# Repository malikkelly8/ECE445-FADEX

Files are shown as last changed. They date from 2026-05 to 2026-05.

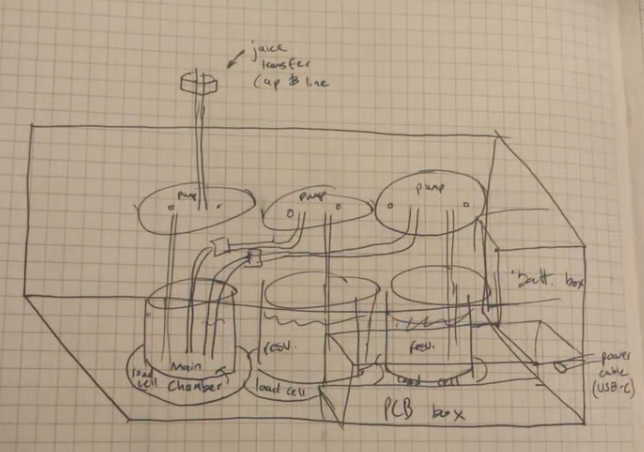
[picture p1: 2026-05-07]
Images/homebasedDesign.png

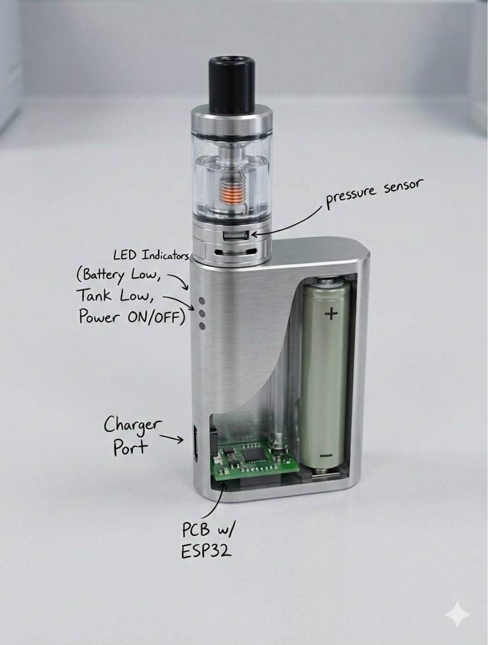
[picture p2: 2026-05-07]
Images/vape.jpg

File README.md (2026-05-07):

# FadeX - Automated Nicotine Tapering System

FadeX is an adaptive nicotine tapering prototype developed for ECE 445. The project explores a safer, feedback-based way to reduce nicotine concentration over time while preserving the user's familiar puff routine. Instead of forcing large manual concentration jumps, FadeX uses puff behavior, user check-ins, and embedded control logic to calculate a gradual taper and prepare a target mixture.

## Team Members

- **Malik Kelly** - Tapering algorithm, app/chatbot interface, ESP32 integration support
- **Justin Leith** - Project management, mechanical design, optical sensing support
- **Ian Zentner** - MCU logic, PCB design, hardware integration

## Final Prototype Overview

The final FadeX prototype centers on a **Homebase ESP32** that coordinates communication, dosing logic, pump control, load-cell feedback, and concentration sensing. A simplified **Handheld ESP32** is used to record puff activity and send puff-session data to the homebase. The system was demonstrated using a nicotine surrogate rather than real nicotine for safety.

The final architecture includes:

- **Homebase Controller:** ESP32-based controller that runs the tapering algorithm, receives puff data, controls pumps, reads load cells, and manages safety logic.
- **Handheld Puff Input:** Simplified ESP32 handheld with a puff button that records puff count/session duration and sends data to the homebase through ESP-NOW.
- **Fluid Delivery System:** Peristaltic pumps used to deliver concentrate/surrogate and diluent into a mixing reservoir.
- **Load-Cell Feedback:** HX711 load-cell amplifiers used to tare containers and verify delivered liquid mass.
- **UNCS Concentration Sensing:** UV LED and photodiode circuitry used to support concentration feedback for the vitamin C/ascorbic acid surrogate.
- **User Interface:** Blynk dashboard and/or serial-based FadeX Chatbot used to display system state, collect check-in responses, and guide the demo flow.

## Tapering Algorithm

FadeX calculates the next concentration using puff behavior, treatment week, user survey feedback, and safety limits. The algorithm combines objective usage data with simple self-report inputs so that the taper can slow down or stabilize when relapse risk appears higher.

Core algorithm ideas:

- Puff count and puff duration are collected from the handheld or demo input.
- The user check-in classifies the session as `Better`, `Neutral`, `Struggling`, or `Worse`.
- Trigger questions are only asked when the user reports `Struggling` or `Worse`.
- Scenario codes classify the current user state and guide tapering behavior.
- The next concentration is safety-clamped before pump volumes are calculated.
- Pump delivery is verified using load-cell feedback instead of relying only on timed pumping.

Example equations:

```text
A = 1.0 + S + (1.0 - Mu)
C_next = clamp(C_current - 0.28A, 0.5%, 5.0%)
V_concentrate = (C_next / 5.0) * V_total
V_diluent = V_total - V_concentrate
```

## Repository Structure

```text
/Code/              Firmware sketches, tests, and integration code
/Images/            Diagrams, presentation graphics, screenshots, and verification visuals
/Notebook_Entries/  Chronological lab notebook entries and engineering logs
/PCB/          PCB schematics, pinout references, and hardware design files
```

Some folders may contain uploaded final report materials, figures, or archived versions of earlier designs.

## Key Subsystem Tests

The project was developed through modular tests before final integration:

- ESP32 programming and MAC address identification
- ESP-NOW handheld-to-homebase puff communication
- Pump direction, flow-rate, and volume delivery tests
- Load-cell calibration and tare verification
- Water-by-weight dispense testing
- UV LED PWM output testing
- Photodiode ADC readout testing
- Blynk dashboard and FadeX Chatbot workflow testing
- Final integrated dosing and demo flow testing

## Safety Notes

The course prototype used water and vitamin C/ascorbic acid surrogate solutions instead of nicotine for safety. The firmware and demo flow include safety-oriented behavior such as load-cell taring, staged pump pulses, maximum mixing-volume checks, and emergency stop commands. The homebase controller is responsible for safety-critical pump control rather than relying only on the app interface.

## Project Tracking and Engineering Notebook

- `/Notebook_Entries/` contains chronological lab notebook entries documenting objectives, design decisions, testing, debugging, and final outcomes.
- `/Images/` contains visuals used for reports, slides, flowcharts, and verification documentation.
- The GitHub Project/Kanban board was used during development to track subsystem progress and remaining demo tasks.

## Final Deliverables

Final project materials include the final paper, video assignment, lab notebook entries, subsystem test code, algorithm visuals, and final demo documentation.

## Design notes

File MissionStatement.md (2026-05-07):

# FadeX Mission Statement

FadeX exists to explore a safer, more adaptive path for nicotine tapering by combining user behavior data, embedded control, and feedback-based fluid delivery. Traditional cessation tools often separate nicotine reduction from the habitual puff routine, while manual tapering forces users into large concentration jumps that can increase withdrawal and relapse risk. FadeX addresses this gap by using puff activity, user check-ins, and a controlled mixing system to calculate gradual concentration changes that are easier for the user to follow.

Our mission is to demonstrate that nicotine reduction can be automated, personalized, and safety-aware. The FadeX prototype uses a homebase ESP32 controller, handheld puff input, pump-based liquid delivery, load-cell mass verification, and optical concentration sensing with a safe surrogate solution. This system is designed to show how future cessation devices could reduce nicotine exposure over time while preserving behavioral continuity, improving transparency through a user interface, and maintaining firmware-level safety limits.

FadeX is not intended to encourage vaping or recreational nicotine use. Its purpose is to support cessation-focused engineering by showing how adaptive algorithms, sensor feedback, and embedded safeguards can work together to guide users toward lower dependence.

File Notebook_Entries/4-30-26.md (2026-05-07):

## Entry 4: Final Presentation and Feedback

**Date:** 4/30/26  

**Objective:** Present the final FadeX project and receive feedback from course staff.

**Work Completed:**  
The team delivered the final presentation to explain the project motivation, design, implementation, testing, and conclusions. The presentation described the shift from the original full vape concept to a safer homebase-centered prototype using pumps, load cells, ESP32 control, and app/serial interaction. We explained the adaptive algorithm, including how puff behavior and user state affected concentration decisions. We also discussed safety measures such as using a surrogate instead of nicotine, load-cell verification, pump limits, and emergency stop behavior.

**Results / Decisions:**  
The final presentation helped clarify the completed design and the remaining limitations. The team showed that FadeX was not just a mechanical mixing system but an adaptive control system that connected user behavior to physical dosing. Feedback from the presentation helped guide what needed to be emphasized in the final paper, especially the actual implemented design, verification results, and future work.

**Next Step:**  
Update the final paper to match the final implemented system and include accurate descriptions of hardware, software, testing, and limitations.

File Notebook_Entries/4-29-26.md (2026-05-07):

## Entry 3: Final Presentation Preparation

**Date:** 4/29/26  

**Objective:** Prepare the final presentation slides and organize the project story for a clear technical presentation.

**Work Completed:**  
The team prepared the final presentation by organizing the project into introduction, objective, design, results, and conclusion sections. I focused on the objective and algorithm-related slides, including the problem being solved, the adaptive tapering logic, the main equations, scenario codes, and how the hardware subsystems supported the algorithm. The presentation emphasized the flow from puff behavior to algorithm decision to physical fluid delivery. The team also refined visuals so that graphs, flowcharts, equations, and stage diagrams were readable and did not overlap.

**Results / Decisions:**  
The team decided that the presentation should be organized around the algorithm flow rather than only listing hardware subsystems. This made it easier to explain why load cells, pumps, app inputs, and the UV/photodiode sensor mattered. The final presentation connected the design decisions back to the original problem of helping users taper nicotine without large manual concentration jumps.

**Next Step:**  
Rehearse the presentation, finalize slide visuals, and prepare for questions about implementation changes, verification, and safety.

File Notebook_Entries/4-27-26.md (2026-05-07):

## Entry 1: Final Demo Setup and System Readiness

**Date:** 4/27/26  

**Objective:** Prepare the FadeX prototype for final demonstration and verify that the most important subsystems were ready to show.

**Work Completed:**  
The team reviewed the final demo setup and checked which subsystems could be demonstrated reliably. The focus was on showing the homebase control system, pump delivery behavior, load-cell feedback, app or serial interaction, and the adaptive algorithm. Since the project had changed from the original fully integrated vape concept into a safer homebase-centered demonstration, the final setup emphasized controlled fluid mixing, puff-data input, and algorithm-driven concentration adjustment. We also reviewed backup plans in case Blynk connectivity, ESP-NOW communication, or pump/load-cell integration failed during the demo.

**Results / Decisions:**  
The team decided that the final demo should prioritize reliability and clarity. The most important story was that FadeX could collect usage information, calculate a next concentration, and physically dose liquid using feedback rather than blind timing alone. The demo sequence was kept controlled so that the evaluators could clearly see each major subsystem contribute to the final result.

**Next Step:**  
Run final checks on the ESP32 firmware, pumps, load cells, communication path, and user-facing interface before presenting.

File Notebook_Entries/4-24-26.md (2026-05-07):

## Entry 5: Final Demo Risk Review

**Date:** 4/24/26  

**Objective:** Identify the highest-risk integration issues remaining before the final demo.

**Work Completed:**  
After the mock demo and presentation preparation, the team reviewed what still needed to work reliably for the final demonstration. The main risks were reliable pump delivery, load-cell calibration, communication between handheld and homebase, Blynk connectivity, clear demo steps, and concentration verification with the UV/photodiode sensor. We also discussed fallback options, including using the serial monitor as a backup interface if Blynk or wireless communication became unreliable.

**Results / Decisions:**  
The team decided that the final demo needed a controlled sequence instead of an open-ended test. The demo should show puff input, algorithm calculation, app/chatbot feedback, pump delivery, and safety behavior in a repeatable order. The team also recognized that fallback paths were important because wireless systems and hardware integration could fail under demo conditions.

**Next Step:**  
Prepare a final demo script, continue hardware debugging, and make sure each subsystem has a working backup test.

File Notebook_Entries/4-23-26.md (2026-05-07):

## Entry 4: Blynk Dashboard and Chatbot Demo Flow

**Date:** 4/23/26  

**Objective:** Improve the user-facing demo by using Blynk and the FadeX Chatbot to guide the dose workflow.

**Work Completed:**  
I worked on the app/demo flow using Blynk virtual pins and the FadeX Chatbot terminal interface. The dashboard included values such as current concentration, next concentration, puff count, puff duration, survey score, trigger code, scenario code, nicotine volume, diluent volume, money saved, milestone progress, clinician override, prime command, run dose command, and puff button. The chatbot was designed to guide the user through a session by showing current status, collecting survey input, asking about triggers only when needed, and preparing the dose calculation. I also worked through issues with terminal clearing, repeated messages, and the order of chatbot prompts.

**Results / Decisions:**  
The team decided that the Blynk dashboard would be the main app interface, while the chatbot would make the demo easier to follow. The app would display system values, and the chatbot would explain what the system was doing step by step. However, the homebase ESP32 would still remain responsible for dosing logic and safety-critical pump control.

**Next Step:**  
Refine the chatbot prompt order, reduce repeated terminal output, and ensure the run-dose workflow asks the right questions before calculating the next concentration.

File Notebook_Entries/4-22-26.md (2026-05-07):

## Entry 3: Algorithm and Stage Visual Development

**Date:** 4/22/26  

**Objective:** Create visual materials that clearly explained the adaptive algorithm and the hardware stages for the mock/final presentation.

**Work Completed:**  
I worked on presentation graphics for the algorithm overview and stage-based design slides. The algorithm was organized into major stages: detecting puff activity, collecting survey/user state information, calculating the next concentration, and dispensing/verifying the final mixture. I also created or refined visuals for the adaptive decision table, equations, and stage-specific hardware functions. Several figures required polishing so that text fit inside boxes, arrows were not cut off, and graphs did not cover important labels.

**Results / Decisions:**  
The team decided that visuals would be essential for explaining the project quickly. The algorithm overview slide needed to include the main equations and variable definitions, while the stage slides needed to show how the hardware interacted with the software. This helped turn a complex system into a presentation sequence that was easier to follow.

**Next Step:**  
Finalize the algorithm graphics, stage visuals, and equation/definition slide for the mock presentation and final report.

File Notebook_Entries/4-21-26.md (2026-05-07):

## Entry 2: Mock Presentation Slide Planning

**Date:** 4/21/26  

**Objective:** Build a short mock presentation that explained the project objective, algorithm, and hardware flow clearly.

**Work Completed:**  
The team divided mock presentation responsibilities across the required slide categories: title, introduction, objective, design, and conclusion. I focused on the objective slide and the algorithm-based design slides. The presentation flow was planned around explaining the high-level algorithm first, then breaking down each hardware subsystem based on where it appears in the algorithm. This included puff detection and usage tracking, adaptive decision logic, fluid delivery with pumps/load cells, and concentration feedback using the UV/photodiode system.

**Results / Decisions:**  
The team decided that the presentation should explain the algorithm as the main story and then show how the hardware supports each step. This made the presentation more coherent than listing hardware blocks separately. It also helped connect the user problem, software algorithm, and physical mixing system in a way that non-specialists could follow.

**Next Step:**  
Create and polish visuals for the objective slide, algorithm overview, stage-based hardware slides, and final conclusion.

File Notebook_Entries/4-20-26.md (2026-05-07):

## Entry 1: Mock Demo Preparation

**Date:** 4/20/26  

**Objective:** Prepare a focused mock demo that showed meaningful subsystem progress and clarified what still needed to be finished before the final demo.

**Work Completed:**  
The team reviewed the remaining hardware, software, and presentation tasks for the mock demo week. We focused on demonstrating the most important parts of the system: ESP32 control, pump behavior, load-cell sensing, app or serial interface interaction, and the adaptive algorithm flow. Since not every subsystem was fully integrated yet, the goal was to present working pieces clearly and explain how they would connect in the final system. I worked on organizing the algorithm explanation and app/demo flow so that the control logic could be understood even if the hardware was still being debugged.

**Results / Decisions:**  
The team decided that the mock demo should not try to hide unfinished work. Instead, it should show current progress, identify remaining blockers, and demonstrate that the project had a realistic path to final integration. The mock demo helped reveal which parts needed the most attention before the final week, especially pump/load-cell integration, communication reliability, and a clean user-facing demo flow.

**Next Step:**  
Use mock demo feedback to prioritize final integration tasks and prepare a reliable final demo sequence.

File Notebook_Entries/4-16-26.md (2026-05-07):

## Entry 4: Parts Procurement and Nicotine Contingency Planning

**Date:** 4/16/26  

**Objective:** Review remaining parts procurement issues and develop a backup plan if nicotine could not be used safely in the lab.

**Work Completed:**  
The team discussed uncertainty around using real nicotine and whether safer substitute materials would be needed for the final demo. We also reviewed component sourcing, including possible substitutions for MOSFETs, LED drivers, USB-C parts, and other hardware. Since some parts were coming from different vendors, including DigiKey and Amazon, the team discussed how to keep progress moving even if the final PCB or specialty components were delayed.

**Results / Decisions:**  
The team recognized that a nicotine surrogate might be necessary for safety and feasibility. This decision later supported the use of vitamin C/ascorbic acid as a measurable surrogate for concentration testing. The team also decided to prioritize parts that enabled subsystem testing, even if the exact final hardware was not fully available yet.

**Next Step:**  
Finalize the parts list, continue ordering needed components, and confirm with TAs or course staff what materials could be used safely for demonstration.

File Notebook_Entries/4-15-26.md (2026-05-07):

## Entry 3: Blynk App and User Interface Planning

**Date:** 4/15/26  

**Objective:** Develop the app-side plan for displaying system status and collecting user inputs during the demo.

**Work Completed:**  
I worked on planning the Blynk dashboard and how it would support the FadeX demo. The dashboard needed to show values such as current concentration, next concentration, daily puff count, daily puff duration, survey score, trigger code, scenario code, nicotine volume, diluent volume, milestone progress, and money saved. I also considered how the app could be used to start a dose run, prime pumps, and display algorithm outputs. Since app connectivity could become a risk, I also considered using the serial monitor as a backup control interface.

**Results / Decisions:**  
The team decided that the app should be useful for user-facing interaction but that the ESP32 firmware should remain responsible for safety-critical dosing. This meant the app could collect inputs and display outputs, while the homebase controller would still calculate and enforce dose behavior. Blynk was selected as the main app option because it allowed quick dashboard creation and virtual pins for data exchange.

**Next Step:**  
Create Blynk datastreams, connect the ESP32 to the dashboard, and test whether dashboard values update reliably.

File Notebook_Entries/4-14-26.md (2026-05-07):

## Entry 2: Skeleton Code Test Planning

**Date:** 4/14/26

**Objective:** Define skeleton code tests that could verify basic hardware functionality before full system integration.

**Work Completed:**  
The team discussed a set of small ESP32 test programs for hardware bring-up. These included an ESP32 programming test using a blinking output pin, PWM output for the UV LED driver, ADC input for the photodiode circuit, motor driver tests for the pumps, and HX711/load-cell calibration tests. The goal was to confirm that each circuit could be controlled or read by the ESP32 before merging everything into the final firmware. These tests would also produce simple evidence such as oscilloscope waveforms, serial monitor readings, and visible pump activation.

**Results / Decisions:**  
The team decided that subsystem skeleton code would be safer and easier to debug than immediately building one large program. Each test would isolate one subsystem, making it easier to identify whether a problem came from wiring, code, power, or hardware. This approach became important for later debugging when pump pins, load-cell readings, and UV/photodiode behavior needed to be verified individually.

**Next Step:**  
Write or adapt skeleton code for ESP32 GPIO, pump motor drivers, load cells, UV LED PWM, and photodiode ADC readings.

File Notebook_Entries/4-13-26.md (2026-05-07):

## Entry 1: Mock Demo Planning and Kanban Review

**Date:** 4/13/26  

**Objective:** Prepare for the mock demo by reviewing project status, identifying incomplete tasks, and organizing the remaining hardware/software work.

**Work Completed:**  
The team reviewed the GitHub Kanban board to determine what had been completed and what still needed to be finished before the mock demo. We identified key tasks including finishing the vape/demo layout, completing subsystem skeleton code, and updating the Kanban board with progress. The team discussed how exam and homework schedules would affect the pace of work, so the goal was to focus on practical tasks that would most directly support the demo. I focused on the software and app-facing side of the project, including how the user interface would interact with the ESP32 system.

**Results / Decisions:**  
The team decided that the mock demo should focus on showing working subsystem behavior rather than trying to present the entire final system as complete. The Kanban board became the main snapshot of project progress and helped prioritize the highest-impact tasks.

**Next Step:**  
Continue updating the Kanban board and focus on skeleton tests for the major hardware subsystems.

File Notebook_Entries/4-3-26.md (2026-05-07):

## Entry 4: Hardware Testing Strategy and Breadboard Planning

**Date:** 4/3/26  

**Objective:** Plan the hardware tests needed before full PCB integration and decide how to use breadboard testing effectively.

**Work Completed:**  
The team discussed PCB printing, ESP32 programming, power wiring, and whether to begin testing on a breadboard while waiting for PCB hardware. We identified that breadboard testing could help verify the most important functions early, including pump direction, pump flow rate, motor driver logic, load-cell communication, and ESP32 pin behavior. We also discussed the importance of matching breadboard pins to expected PCB pins as much as possible so that test code could later transfer to the final board with minimal changes.

**Results / Decisions:**  
The team decided that breadboard testing was necessary to reduce schedule risk. Waiting for the PCB before testing every subsystem would create too much uncertainty. The plan was to build modular tests first, then later merge working subsystem code into the final integrated homebase firmware.

**Next Step:**  
Begin breadboard tests for pump drivers and load cells, then record results for verification and debugging.

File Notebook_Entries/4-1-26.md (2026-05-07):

## Entry 3: Verification and Flowchart Planning

**Date:** 4/1/26  

**Objective:** Develop verification tasks and improve the visual explanation of the FadeX algorithm and subsystem flow.

**Work Completed:**  
The team discussed verification planning, flowcharts, and how to show hardware/software integration clearly. I worked on organizing the algorithm flow into a visual structure that could be used later for slides and documentation. The flow needed to show how puff detection, user state, usage trends, concentration calculation, pump volume calculation, and dashboard updates were connected. The team also discussed verification tests for different subsystems, such as ESP32 programming, pump activation, load-cell readings, UV LED PWM output, photodiode ADC readings, and wireless communication.

**Results / Decisions:**  
The team decided that each subsystem needed a clear verification path. The algorithm flowchart would help explain the software side, while hardware verification tests would prove that each physical subsystem could support the algorithm. This work also helped prepare for progress demo and final presentation materials.

**Next Step:**  
Create refined visuals for the algorithm flow and begin writing or collecting skeleton test code for hardware verification.

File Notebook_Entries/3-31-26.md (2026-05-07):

## Entry 2: GitHub Repository and Kanban Access

**Date:** 3/31/26  

**Objective:** Improve project coordination by making sure team members could access shared code and task-tracking resources.

**Work Completed:**  
The team discussed GitHub repository access, Kanban board visibility, and how to keep code and documentation organized. I worked on resolving access issues so that I could view or contribute to the repository and project board. The team also discussed whether updates should be shared through GitHub, screenshots, text files, or exported figures. Since the project involved multiple subsystems and several people working in parallel, having a shared task board became important for tracking what was finished, what was blocked, and what still needed to be assigned.

**Results / Decisions:**  
The team decided that the Kanban board and GitHub repository should become the main coordination tools for software, verification tasks, and documentation. This helped reduce confusion about task ownership and made it easier to prepare evidence for progress demos and the final report.

**Next Step:**  
Continue updating the Kanban board with hardware tests, software tasks, app work, and documentation progress.

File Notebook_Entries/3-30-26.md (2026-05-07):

## Entry 1: Individual Progress Report Preparation

**Date:** 3/30/26  

**Objective:** Prepare the individual progress report by documenting personal contributions, current project status, and remaining risks.

**Work Completed:**  
I worked on organizing my individual progress report for the course deadline. The report summarized my contributions to the FadeX project, especially the adaptive tapering algorithm, app/interface planning, flowchart development, and software-side integration planning. I also reviewed the project schedule and compared the original design document goals with the current implementation status. This helped identify which parts of the project were progressing and which parts still needed more testing, such as pump control, load-cell calibration, wireless communication, and concentration sensing.

**Results / Decisions:**  
The progress report helped clarify my role in the project. My main responsibilities were centered on algorithm development, user interaction, app/dashboard planning, and connecting the software logic to the hardware subsystems. It also made clear that the project needed to move quickly from planning into subsystem testing.

**Next Step:**  
Submit the individual progress report and continue developing the algorithm and app-side workflow for the upcoming demos.

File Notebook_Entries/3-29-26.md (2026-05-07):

## Entry 4: Breadboard-to-PCB Transition Planning

**Date:** 3/29/26  

**Objective:** Plan how breadboard testing would transition into PCB testing without changing the software structure too much.

**Work Completed:**  
The team discussed how to organize code and hardware tests so that the same firmware concepts could work on both breadboard and PCB setups. We identified that pin definitions should be isolated near the top of each sketch so that changing from breadboard pins to PCB pins would be straightforward. We also discussed the need for small subsystem sketches, such as pump tests, load-cell calibration tests, UV LED PWM tests, photodiode ADC tests, and ESP32 communication tests.

**Results / Decisions:**  
The team decided that subsystem test sketches would be important for debugging. Instead of immediately building one large final program, the project would benefit from smaller test programs that each verified a single hardware function. This decision later made it easier to debug pumps, load cells, ESP-NOW, Blynk, and UNCS separately before integration.

**Next Step:**  
Begin creating skeleton code tests for each hardware subsystem and prepare for the individual progress report due the following week.

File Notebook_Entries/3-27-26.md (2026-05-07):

## Entry 3: Algorithm Flowchart and Documentation Update

**Date:** 3/27/26  
**Objective:** Improve documentation of the adaptive tapering algorithm and make the algorithm easier to explain for future reports and presentations.

**Work Completed:**  
The team worked on making the algorithm easier to visualize and explain. The algorithm was organized around several major steps: detecting puff activity, measuring puff duration and count, collecting user state information, computing the next concentration, applying safety limits, calculating pump volumes, and updating the user interface. This helped connect the software algorithm to the physical hardware subsystems, since puff data came from the handheld, concentration calculations ran on the homebase, and final dosing was performed by pumps and verified with sensors.

**Results / Decisions:**  
The team decided that the algorithm should be presented as a staged flow rather than just equations. This made it easier to explain how hardware inputs influenced the final concentration. The flowchart also helped reveal which variables needed to be displayed in the app or serial interface, including current concentration, next concentration, puff count, puff duration, scenario code, and dose volumes.

**Next Step:**  
Create or refine an algorithm flowchart and use it to guide software implementation.

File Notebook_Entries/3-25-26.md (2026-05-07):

## Entry 2: PCB Order and Hardware Availability Planning

**Date:** 3/25/26  

**Objective:** Track PCB ordering deadlines and plan around expected hardware availability.

**Work Completed:**  
The team reviewed the PCB ordering timeline and the fourth-round JLCPCB order deadline. Since the final system depended on custom PCB hardware, we discussed which circuits needed to be finalized and what could still be tested on a breadboard. The hardware plan included preparing for ESP32 bring-up, pump driver testing, load-cell amplifier testing, and UV/photodiode circuit validation. We also discussed the importance of matching breadboard pinouts to the PCB schematic so that code written during testing could transfer more easily to the final PCB.

**Results / Decisions:**  
The team decided that code should be written with PCB pin assignments in mind whenever possible, even if the immediate test was performed on a breadboard. This would reduce later rework when switching from breadboard hardware to the PCB. The team also recognized that some hardware testing would need to happen before the final PCB arrived to keep the schedule realistic.

**Next Step:**  
Confirm the latest schematic pin assignments and begin writing test code that can be reused for PCB bring-up.

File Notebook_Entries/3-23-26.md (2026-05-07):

## Entry 1: Post-Spring-Break Project Reset

**Date:** 3/23/26  

**Objective:** Re-establish project priorities after spring break and identify the most important tasks for hardware and software progress.

**Work Completed:**  
After spring break, the team reviewed the current project status and compared it against the design document schedule. The main focus was shifting from documentation and planning into physical testing and implementation. We reviewed which subsystems needed immediate attention, including ESP32 programming, pump control, load-cell reading, UV LED/photodiode sensing, and app or serial interface development. The team also discussed how the project might need to use breadboard testing while waiting for PCB fabrication or parts delivery.

**Results / Decisions:**  
The team decided that modular testing was still the safest path forward. Rather than waiting for every part of the final system, each subsystem would be tested independently as soon as enough hardware was available. This approach reduced the risk of discovering integration issues too late in the semester.

**Next Step:**  
Begin preparing breadboard tests and update the project task board with post-break priorities.

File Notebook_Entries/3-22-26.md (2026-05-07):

## Entry 4: Post-Break Hardware Bring-Up Plan

**Date:** 3/22/26  

**Objective:** Prepare a hardware testing plan for when the team returned from spring break.

**Work Completed:**  
The team outlined the hardware bring-up tasks that would need to happen after break. These included verifying ESP32 programming, checking power rails, testing pump drivers, confirming pump direction and flow, reading load-cell values through HX711 amplifiers, generating PWM for the UV LED, and reading ADC voltage from the photodiode circuit. The goal was to test each subsystem independently before combining them into the full Home Base system.

**Results / Decisions:**  
The team decided that the post-break hardware plan should be modular and evidence-based. Each test should produce a measurable result, such as a serial monitor reading, oscilloscope waveform, measured voltage, pump output volume, or load-cell calibration value. This would make debugging easier and provide material for verification documentation.

**Next Step:**  
Return from break prepared to run subsystem tests, document results, and update the Kanban board with completed hardware milestones.

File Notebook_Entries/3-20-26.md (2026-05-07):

## Entry 3: App Interface and User Interaction Planning

**Date:** 3/20/26  

**Objective:** Plan how the user would interact with FadeX through an app or backup interface.

**Work Completed:**  
The team considered what information the user should see and what inputs the system would need to collect. Possible app values included current concentration, next concentration, puff count, puff duration, treatment week, dose volumes, battery or device status, and progress toward quitting. We also considered whether the app should directly control dosing or only provide inputs and display status while the ESP32 firmware handled safety-critical decisions.

**Results / Decisions:**  
The team decided that the app should act as the user interface and data display, but not as the only safety controller. This meant that the Home Base firmware should still be able to enforce pump limits, dose calculations, and emergency stop behavior even if app communication failed. This decision made the system safer and more robust for demo conditions.

**Next Step:**  
Create a dashboard plan and determine which variables need to be displayed or controlled by the app.

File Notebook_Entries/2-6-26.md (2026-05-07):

## Entry 3: Early Risk Identification

**Date:** 2/6/26  

**Objective:** Finalize the early project approval direction and identify the first technical risks.

**Work Completed:**  
The team reviewed what needed to be included for project approval and discussed the project’s main feasibility risks. These included whether small pumps could accurately dispense liquid, whether the system could safely measure or estimate nicotine concentration, whether wireless communication would be reliable, and whether the design could be demonstrated within the semester timeline. We also discussed user safety constraints, such as limiting dose size, tracking usage, and preventing uncontrolled nicotine delivery.

**Results / Decisions:**  
The team identified fluid delivery accuracy, sensor feedback, and safety logic as core verification areas. We also decided that the project would need a clear separation between the user-facing interface and the safety-critical homebase controller. Early algorithm equations were not finalized yet, but the team agreed that the concentration update should depend on both puff behavior and user condition.

**Next Step:**  
Move into subsystem planning, assign responsibilities, and start building a preliminary BOM and schedule.

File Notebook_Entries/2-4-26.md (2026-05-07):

## Entry 2: Project Direction and System Planning

**Date:** 2/4/26 

**Objective:** Convert the early FadeX idea into a clearer project plan that could be explained for project approval.

**Work Completed:**  
After the third class meeting, the team refined the problem statement and discussed how FadeX would address nicotine tapering in a safer and more controlled way. We focused on the idea that a fixed taper schedule may not respond well to real user behavior, so the device should collect usage data and adjust the nicotine concentration over time. The team also started outlining the main engineering problems: detecting puff activity, calculating a target concentration, physically mixing the correct ratio of concentrate and diluent, and providing a user-facing interface.

**Results / Decisions:**  
The project direction became more focused around an adaptive homebase system rather than only a modified vape device. The team decided that objective usage data and user input should both influence the tapering algorithm. This became an important design decision because it tied the software algorithm directly to the hardware requirements for sensing, pumping, and communication.

**Next Step:**  
Prepare the project approval submission and begin listing required components, including ESP32 boards, pumps, sensors, and possible concentration measurement methods.

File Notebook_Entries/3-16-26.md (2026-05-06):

## Entry 1: Spring Break Remote Planning

**Date:** 3/16/26  

**Objective:** Continue project planning during spring break and identify tasks that could be completed without full lab access.

**Work Completed:**  
This week was spring break, so the team did not have the same level of regular in-person lab work. Instead, the focus shifted toward remote planning, documentation, algorithm development, and preparing for hardware bring-up after break. We reviewed which tasks could still move forward without full lab access, including refining the tapering algorithm, reviewing the design document, checking the parts list, and planning the app interface. The team also considered what tests would need to happen immediately after break once hardware access and part availability improved.

**Results / Decisions:**  
The team decided that spring break should still be used to reduce later integration risk. Even without major physical testing, software planning and documentation could continue. The main decision was to use the break to clarify the algorithm, app flow, and upcoming hardware test sequence so that the team could return ready for subsystem testing.

**Next Step:**  
Continue refining the algorithm and app plan, then return from break ready to test pumps, load cells, ESP32 programming, and sensing circuits.

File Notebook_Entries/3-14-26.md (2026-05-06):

## Entry 4: Spring Break Work Planning

**Date:** 3/14/26 

**Objective:** Plan work that could be completed during or around spring break to keep the project moving.

**Work Completed:**  
The team discussed how to continue making progress despite the upcoming spring break. We reviewed the need to push forward on PCB design, parts ordering, software skeleton code, and mechanical planning. The team also discussed whether some work could be done remotely, such as algorithm development, app planning, documentation, and schematic review, while physical assembly and testing would depend on part availability.

**Results / Decisions:**  
The team decided that spring break should not pause the project completely. Software, documentation, and planning tasks could continue even if physical hardware work slowed down. This was important because final integration would require the hardware and software pieces to be ready at roughly the same time.

**Next Step:**  
Continue software planning, follow up on parts and chemical ordering, and prepare for hardware bring-up after spring break.

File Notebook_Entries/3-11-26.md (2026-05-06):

## Entry 3: Pump and Chemical Strategy

**Date:** 3/11/26  

**Objective:** Evaluate pump options and identify a safe chemical strategy for demonstrating concentration measurement.

**Work Completed:**  
The team continued discussing pump options and whether higher-cost precision pumps were justified for the project. Since accurate dosing was one of the most important requirements, the team considered whether spending more on pumps or related driver hardware could reduce risk. We also continued discussing the challenge of replacing nicotine for the demonstration. The team needed a chemical surrogate that would be safer to handle than nicotine but still measurable by the selected sensing method.

**Results / Decisions:**  
The team recognized that pump accuracy and chemical sensing were linked: even if the pumps delivered the correct volume, the system still needed a way to verify concentration. This supported the continued investigation of a UV-based sensing approach and a safer surrogate material. The team also recognized that final pump selection had to balance cost, lead time, electrical complexity, and accuracy.

**Next Step:**  
Continue sourcing pumps, verify lead times, and research surrogate chemicals that can be detected with optical sensing.

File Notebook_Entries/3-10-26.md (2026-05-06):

## Entry 2: Meeting With Shrey and Detector Housing Discussion

**Date:** 3/10/26  
**Objective:** Discuss concentration sensing, detector housing needs, pump options, and software direction with Shrey.

**Work Completed:**  
The team met with Shrey and discussed several important design issues. For the detector system, we asked about creating a housing and identified the need to send specifications for the optical components along with a sketch of the proposed layout. The team also discussed chemical ordering and the need to coordinate with Elbashir. Pump selection was another major topic, especially whether Bartel pumps would meet our accuracy needs and arrive in time. The team also discussed software topics such as using a medical record number instead of personally identifiable information, estimating the maximum liquid volume needed for a taper schedule, and using usage data to adjust tapering over time.

**Results / Decisions:**  
The meeting helped clarify that concentration measurement and pump selection were still high-risk areas. The team decided to keep investigating detector housing, pump availability, chemical ordering, and tapering strategy. The discussion also reinforced the idea that the algorithm should not only follow a fixed schedule but should collect usage data and adjust the taper based on behavior.

**Next Step:**  
Send detector part specifications and layout sketches for housing support, contact pump vendors if needed, and continue refining the tapering algorithm.

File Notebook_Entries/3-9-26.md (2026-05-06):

## Entry 1: Breadboard Demo Planning

**Date:** 3/9/26  

**Objective:** Prepare for the breadboard demo by identifying which hardware and software functions could be demonstrated before full PCB integration.

**Work Completed:**  
The team reviewed the upcoming breadboard demo expectations and focused on creating tests that could prove early subsystem functionality. We discussed which parts of the system were ready to test, including ESP32 programming, pump driver outputs, load-cell reading, and early software logic. The team also discussed how to present the project even if all final parts were not available yet. The breadboard plan focused on demonstrating progress toward the Home Base mixing system rather than trying to show the full final vape design.

**Results / Decisions:**  
The team decided that the breadboard demo should emphasize modular subsystem tests. The key goal was to show that the ESP32 could control outputs, communicate with sensors, and eventually coordinate the pumps. This approach made the demo more realistic because the PCB and final mechanical system were still under development.

**Next Step:**  
Prepare breadboard wiring, write simple ESP32 test sketches, and collect evidence of working hardware tests.

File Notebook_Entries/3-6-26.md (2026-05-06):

## Entry 4: Verification Planning for Breadboard Demo

**Date:** 3/6/26  

**Objective:** Turn the design review plan into concrete subsystem tests for the upcoming breadboard demo.

**Work Completed:**  
The team began planning verification tests that could be performed before full system integration. Proposed tests included programming the ESP32 and confirming GPIO output, driving pumps through motor drivers, reading load-cell data through HX711 amplifiers, checking ADC input from the photodiode circuit, generating PWM for the UV LED, and sending simulated puff data through the software. The team also discussed how the adaptive algorithm could be tested in simulation before being connected to real hardware.

**Results / Decisions:**  
The team decided that the breadboard demo should focus on showing measurable progress rather than a fully integrated final product. The most important demo goals were proving that the ESP32 could control hardware, that pumps could move liquid, that sensors could produce readable values, and that the algorithm could calculate a next concentration from user or puff inputs. This created a clearer testing path for the next week.

**Next Step:**  
Build the first breadboard tests, write simple ESP32 bring-up code, and prepare evidence such as serial monitor outputs, oscilloscope waveforms, and photos of the test setup.

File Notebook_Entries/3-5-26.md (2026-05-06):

## Entry 3: PCB Planning and Parts Ordering

**Date:** 3/5/26  

**Objective:** Prepare for the second-round PCB order deadline and identify which circuits needed to be finalized or revised.

**Work Completed:**  
The team reviewed the circuits that needed to be included on the custom PCBs, including the ESP32 controller, power regulation, pump driver connections, load-cell amplifier connections, photodiode/UV sensing circuitry, and handheld vape control circuitry. We also compared this PCB plan against the parts list from the design document to make sure the required components were accounted for. Because several parts had long lead times, the team discussed ordering parts quickly while keeping a breadboard fallback plan available.

**Results / Decisions:**  
The team decided that the PCB design should remain modular so individual circuits could be tested separately. This was important because the final system included several uncertain subsystems, and a single PCB issue could delay the entire project. The team also kept the option of breadboarding the Home Base control system if the PCB arrived late or required revision.

**Next Step:**  
Submit or prepare the PCB order, continue component sourcing, and begin writing skeleton code for hardware bring-up tests.

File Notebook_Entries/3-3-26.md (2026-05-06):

## Entry 2: Design Review Feedback and Technical Risk Refinement

**Date:** 3/3/26  

**Objective:** Use design review feedback to identify the highest-risk parts of the project and refine the implementation plan.

**Work Completed:**  
After design review discussions, the team focused on the subsystems most likely to affect final success: pump accuracy, concentration measurement, load-cell feedback, safety logic, and wireless communication. We discussed that the project could not rely only on theoretical pump timing because tubing, pump startup behavior, and liquid movement could introduce error. We also recognized that measuring the final concentration would be difficult if nicotine could not be used directly in the lab, so the team needed to keep investigating safer surrogate chemicals and optical sensing methods.

**Results / Decisions:**  
The team decided that the project should prioritize proof-of-concept testing for the fluid delivery system and concentration sensing system. The design review reinforced the need for modular verification: first prove that the ESP32 can control pumps, then prove that load cells can measure delivered mass, then integrate those results into the algorithm. This helped reduce risk by making each subsystem testable before full system integration.

**Next Step:**  
Update the design plan and begin preparing breadboard tests for pump control, load-cell measurement, and communication.

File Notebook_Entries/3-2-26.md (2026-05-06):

## Entry 1: Design Review Preparation

**Date:** 3/2/26  

**Objective:** Prepare to present the FadeX design document and explain the system architecture, requirements, and verification plan during design review.

**Work Completed:**  
The team reviewed the completed design document and focused on explaining the major design choices clearly. The most important design decision was the two-part architecture: a Home Base mixing station and a Handheld Vaporizer. We prepared to explain how the Home Base would handle the more complex fluidic system, including reservoirs, pumps, load cells, and concentration sensing, while the handheld device would preserve the user’s normal vaping behavior and collect puff data. We also reviewed the high-level requirements for mixing accuracy, adaptive tapering, and wireless communication.

**Results / Decisions:**  
The team decided that the design review should emphasize feasibility, safety, and verification. Instead of only describing the final product idea, we needed to show how each subsystem could be tested independently. The Home Base was framed as the main control and safety platform, while the handheld was framed as the user-facing behavior-tracking device.

**Next Step:**  
Present the design to the instructor and TAs, collect feedback, and revise subsystem plans based on the review.

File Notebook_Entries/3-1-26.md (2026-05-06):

## Entry 7: Design Document Submission and Review Preparation

**Date:** 3/1/26 

**Objective:** Finalize the design document and prepare to present the design decisions during design review.

**Work Completed:**  
The team reviewed the completed design document to make sure the problem statement, solution, block diagram, subsystem requirements, tolerance analysis, cost analysis, schedule, and safety sections were consistent with each other. We checked that the Home Base and Handheld architecture was clearly explained and that each subsystem had measurable requirements and verification procedures. The team also reviewed the references used for nicotine addiction, gradual cessation, ESP32 hardware, pump hardware, load-cell sensing, UV sensing, battery charging, MOSFET switching, and engineering standards.

**Results / Decisions:**  
The final design document became the first complete technical roadmap for the project. It documented the intended system architecture, major technical risks, proposed verification methods, and semester schedule. The team was ready to move into design review with a clearer explanation of why the project used a Home Base mixing system, a handheld vaporizer, adaptive software, and multiple safety layers.

**Next Step:**  
Attend design review, collect feedback from the instructor and TAs, and revise the implementation plan based on the feedback received.

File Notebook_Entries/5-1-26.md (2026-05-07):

## Entry 5: Final Paper and Video Assignment Work

**Date:** 5/1/26  

**Objective:** Begin final documentation by aligning the final paper and video assignment with the actual completed prototype.

**Work Completed:**  
After the final demo and presentation, the team began updating final documentation. This included revising sections that had changed from the original design document, such as communication method, app implementation, nicotine surrogate use, pump/load-cell control, and UNCS concentration sensing. The team also worked on preparing material for the video assignment and final paper. I focused on making sure the algorithm, app interface, and control/safety logic descriptions matched what was actually implemented by the end of the project.

**Results / Decisions:**  
The team decided that the final report should be honest about design changes while still showing engineering progress. The final system should be described as a proof-of-concept adaptive mixing and control platform rather than the exact commercial-style vape described in the early proposal. This made the final documentation more accurate and defensible.

**Next Step:**  
Complete the final paper, submit the video assignment, and prepare the lab notebook for final submission.

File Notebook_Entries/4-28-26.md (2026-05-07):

## Entry 2: Final Demonstration Execution

**Date:** 4/28/26  

**Objective:** Demonstrate the integrated FadeX system to course staff and show progress toward the major design requirements.

**Work Completed:**  
The team performed the final demonstration using the available hardware and software integration. The demo focused on the homebase system receiving user or puff input, running the adaptive algorithm, calculating a target concentration or dose, and using pumps/load-cell feedback to deliver liquid. The team also showed the user-facing interface through Blynk or a serial-based backup workflow, depending on connection reliability. Safety and verification features were emphasized, including load-cell taring, staged pump control, emergency stop behavior, and limits on uncontrolled dosing.

**Results / Decisions:**  
The final demonstration showed that the project had achieved a working proof of concept for adaptive, feedback-based fluid delivery. Some parts of the original proposal changed due to feasibility, safety, and time constraints, but the core idea remained: use user behavior and software control to guide a tapering process, then physically produce a controlled mixture. The demo also provided important evidence for what worked, what needed more refinement, and what would be described in the final report.

**Next Step:**  
Document final demo results, note any limitations, and update the final paper to reflect the actual implemented system.

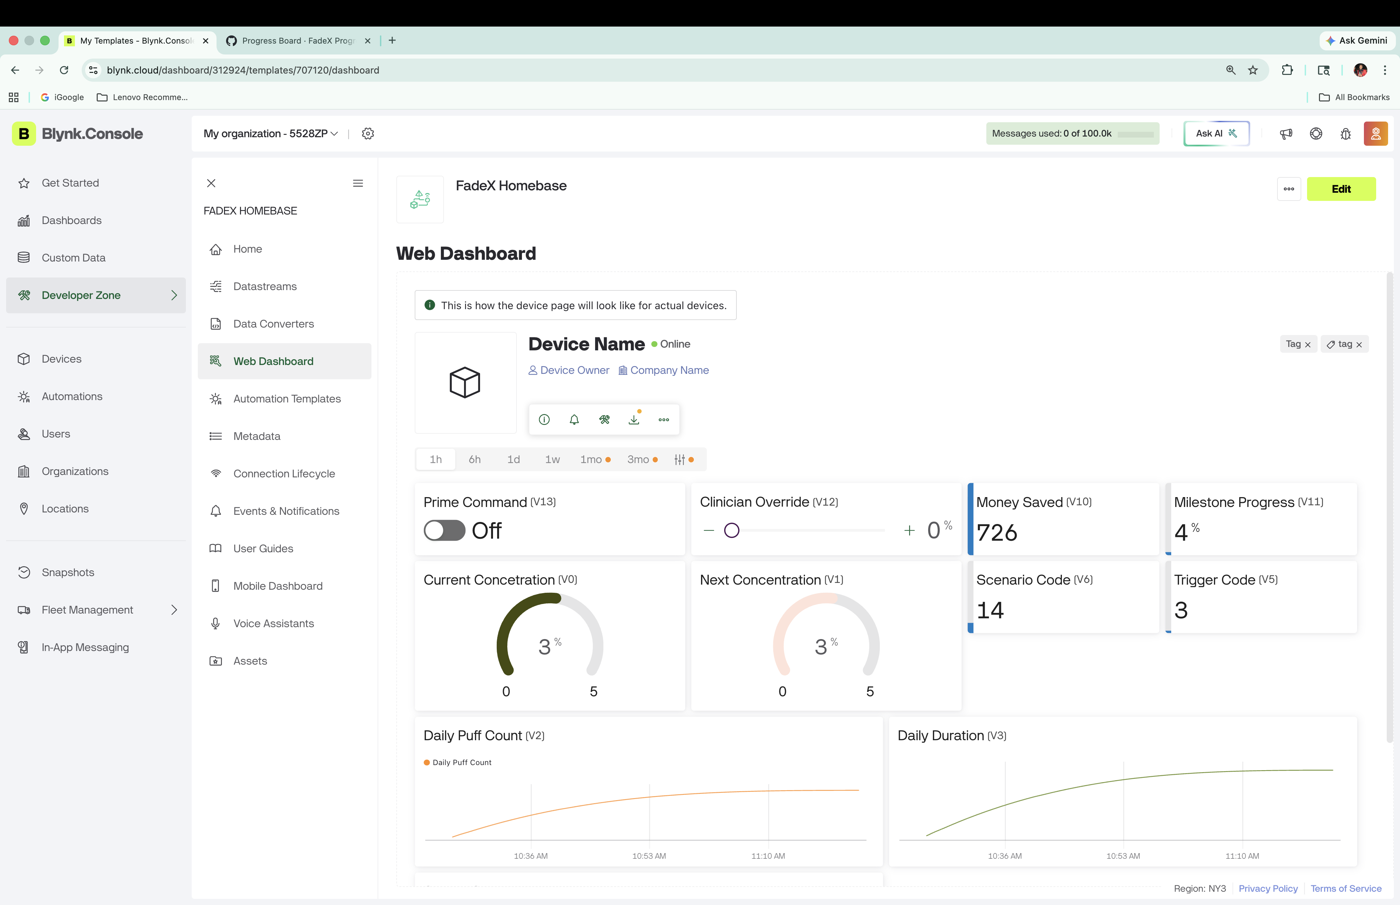
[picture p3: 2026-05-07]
Images/TemplateName.png

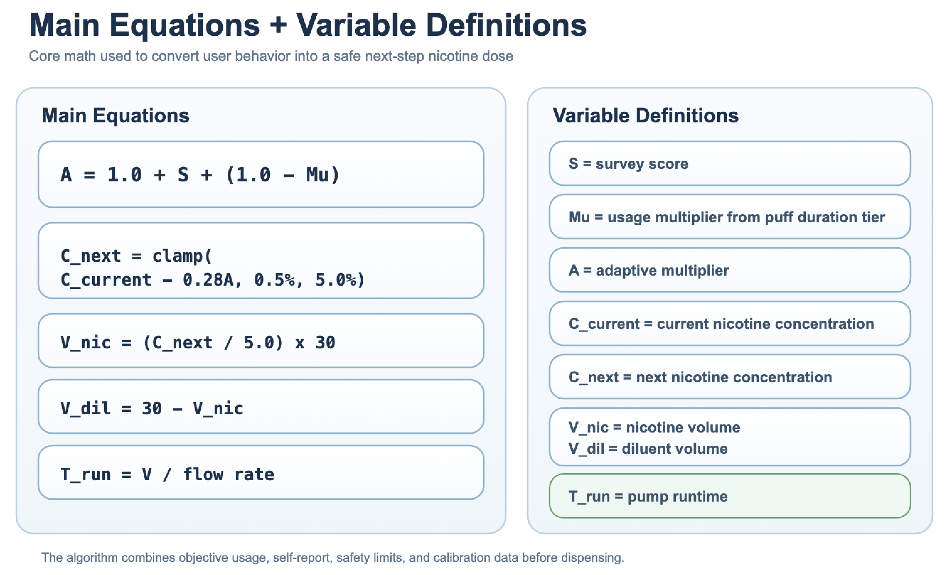
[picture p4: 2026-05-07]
Images/varDefs&mainEqus.png

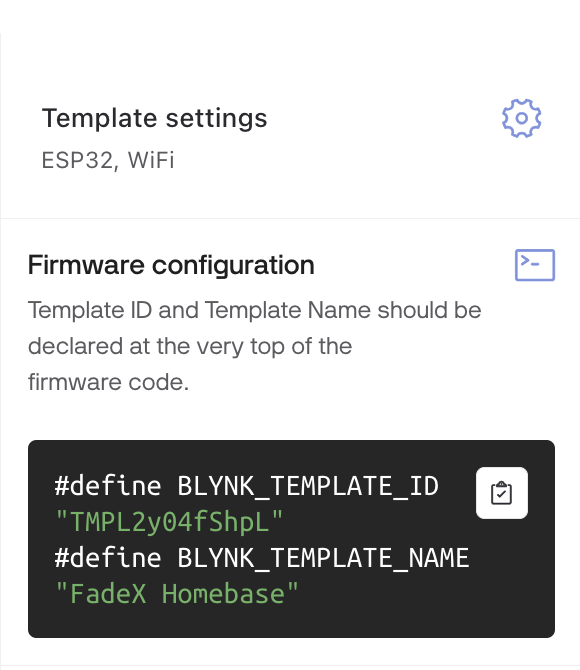
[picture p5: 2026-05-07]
Images/temp.png

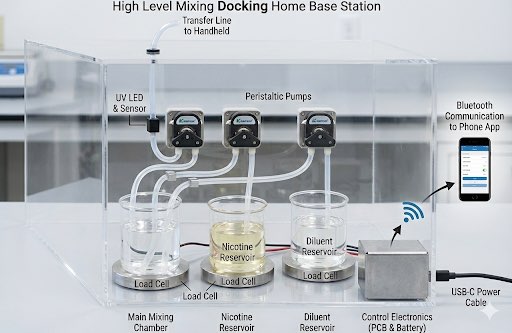
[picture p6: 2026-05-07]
Images/detailed4home.jpg

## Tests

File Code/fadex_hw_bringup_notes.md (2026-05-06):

# FadeX Hardware Bring-Up Notes

## ESP32 Pin Translation

The numbers `27, 28, 31, 30, 33, 36` from the ESP32-WROOM schematic are **module pin numbers**, not Arduino GPIO numbers.

For Arduino code, use:

- Module pin `27` -> `GPIO16`
- Module pin `28` -> `GPIO17`
- Module pin `31` -> `GPIO19`
- Module pin `30` -> `GPIO18`
- Module pin `33` -> `GPIO21`
- Module pin `36` -> `GPIO22`

That means the three DRV8871 channels in the hardware test sketch are:

- Pump 1: `GPIO16`, `GPIO17`
- Pump 2: `GPIO19`, `GPIO18`
- Pump 3: `GPIO21`, `GPIO22`

## Additional Pins Visible In The New Schematic Crops

From the homebase ESP32 crop:

- `DAT1 -> GPIO25`
- `DAT2 -> GPIO26`
- `DAT3 -> GPIO27`
- `DAT4 -> GPIO13`
- `SCLK -> GPIO23`
- `PDO -> GPIO36`
- `UVLEDPWM -> GPIO39` in the current schematic crop

That means the current homebase load-cell plan shown in the schematic is:

- Load Cell 1: `DAT1/GPIO25`, `SCLK/GPIO23`
- Load Cell 2: `DAT2/GPIO26`, `SCLK/GPIO23`
- Load Cell 3: `DAT3/GPIO27`, `SCLK/GPIO23`
- Load Cell 4: `DAT4/GPIO13`, `SCLK/GPIO23`

For the optical path:

- `PDO/GPIO36` is a good ADC input choice.
- `GPIO36` is input-only, which is fine for the photodiode voltage readout.
- `UVLEDPWM/GPIO39` is a problem if we want the ESP32 to generate PWM, because
  `GPIO39` is input-only and cannot drive the LED driver control pin.
- If the PCB is already made, a practical rework is to jumper `GPIO32` to the
  `UVLEDPWM` net or directly to the AL8860 `CTRL` pin.

From the handheld ESP32 crop:

- `PSENS -> GPIO22`
- `PWM -> GPIO23`

## ESP LED Note

On many ESP32 dev boards this LED is on `GPIO2`, but we should change that if we're using another LED

## What Each Sketch Verifies

- HOMEBASE LED TEST
  Blinks the onboard LED on the homebase ESP32 dev board so we can confirm the board is powered, programmed, and running code.

- HANDHELD LED TEST
  Blinks the onboard LED on the handheld ESP32 dev board so we can confirm the board is powered, programmed, and running code.

- SQUAREWAVE TEST
  Confirms the ESP32 was programmed successfully and that a chosen GPIO is really toggling. You should see a square wave on the oscilloscope.

- Motor Driver Test
  Confirms each DRV8871 channel can drive a pump in one direction, reverse polarity, and stop.

- Load Cell Test
  Confirms one HX711 wiring path works and lets you tune the calibration factor with a known weight.

- Load Cell AMP Basic Read

- Photodiode Test
  Confirms the `PDO` analog net reaches `GPIO36` and prints the measured voltage
  in the serial monitor.

- UV LED Test
  Generates PWM on `GPIO32` for a jumper-wire rework into the AL8860 `CTRL`
  input and sweeps the duty cycle so we can verify the waveform on a scope.

## CH340 / Auto-Programming Note

The CH340-to-ESP32 upload circuit is a **hardware test**, not a firmware test.

When you click **Upload** in Arduino IDE, the CH340 and transistor network should toggle the ESP32 `EN` and `IO0` lines to place the chip into bootloader/program mode. The square-wave sketch cannot verify that path directly because it only runs **after** the ESP32 has already been programmed and started.

The right way to scope that upload circuit is:

1. Leave the ESP32 and CH340 connected as in the board design.
2. Probe `EN` and `IO0`.
3. Click **Upload** in Arduino IDE.
4. Look for the expected boot-mode toggling around the start of the upload.

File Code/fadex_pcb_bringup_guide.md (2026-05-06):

# FadeX PCB Bring-Up Guide

Use this order so each subsystem is tested before the full algorithm runs.

## 1. ESP32 MAC / Identity Test

Sketch:
`fadex_esp32_mac_address/fadex_esp32_mac_address.ino`

Steps:

1. Plug in only USB first.
2. In Arduino IDE, select the ESP32 board and the visible `/dev/cu.usbserial-*` port.
3. Set upload speed to `115200` if upload is flaky.
4. Upload the sketch.
5. Open Serial Monitor at `115200` baud.
6. Copy the line labeled `Wi-Fi STA MAC / ESP-NOW MAC`.

Do this once for the homebase ESP32 and once for the handheld ESP32.

Why this matters:
The handheld sends ESP-NOW packets to the homebase station MAC, so the new
homebase MAC must replace the old `HOMEBASE_MAC[]` value in the handheld code.

Current recorded MAC addresses:

| Device | Wi-Fi STA / ESP-NOW MAC |
| --- | --- |
| Homebase PCB ESP32 | `88:13:BF:55:34:80` |
| Handheld vape ESP32 | `88:13:BF:55:35:F0` |

## 2. PCB Pump Driver Test

Sketch:
`fadex_pcb_pump_test/fadex_pcb_pump_test.ino`

PCB connector map:

| Pump | Connector | IN1 net / Arduino pin | IN2 net / Arduino pin |
| --- | --- | --- |
| Pump 1 | J7 | `3190.1.IN1` / GPIO22 | `3190.1.IN2` / GPIO21 |
| Pump 2 | J4 | `3190.2.IN1` / GPIO19 | `3190.2.IN2` / GPIO18 |
| Pump 3 | J9 | `3190.3.IN1` / GPIO33 | `3190.3.IN2` / GPIO4 |

Safe test steps:

1. Upload the sketch with pumps disconnected from fluid first if possible.
2. Connect the 12 V pump supply after upload.
3. Open Serial Monitor at `115200` baud.
4. Type `run 1 f 1.0` to run pump 1 forward for 1 second.
5. Type `run 2 f 1.0` to run pump 2 forward for 1 second.
6. Type `run 3 f 1.0` to run pump 3 forward for 1 second.
7. Type `stop` any time something looks wrong.

If a pump moves fluid the wrong way, that is wiring/polarity direction, not a
code failure. Reverse direction can be checked with `run 1 r 1.0`.

Note: pump 3 uses `GPIO4`, which is an ESP32 boot strapping pin. If upload
fails while the pump-3 driver is connected, disconnect that input during
programming and reconnect it after flashing.

## 3. Load Cell / HX711 Test

Sketch:
`fadex_hx711_round_robin_test/fadex_hx711_round_robin_test.ino`

PCB connector map:

| Channel | Connector | HX711 DOUT net / Arduino pin |
| --- | --- | --- |
| LCA1 | J2 | `DAT1` / GPIO25 |
| LCA2 | J10 | `DAT2` / GPIO26 |
| LCA3 | J13 | `DAT3` / GPIO27 |
| LCA4 | J5 | `DAT4` / GPIO13 |
| Shared SCLK | all four | `SCLK` / GPIO23 |

This sketch tares all four load cells, then asks for the `33.4 g` reference
weight on LCA1, LCA2, LCA3, and LCA4 in order.

## 4. Photodiode ADC Test

Sketch:
`fadex_photodiode_adc_test/fadex_photodiode_adc_test.ino`

PCB pin map:

| Signal | ESP32 Pin |
| --- | --- |
| PDO | GPIO36 / ADC1_CH0 |

Expected behavior:
The serial monitor prints raw ADC counts and estimated voltage. Shining light
or changing the photodiode input should move the reported voltage. Keep any
external test voltage between `0 V` and `3.3 V`.

## 4.5. Water Dose By Weight Test

Sketch:
`fadex_weight_dose_test/fadex_weight_dose_test.ino`

Purpose:
This is the first bridge between the pumps and the load cells. The sketch tares
an empty cup on a selected load cell, runs a selected pump, and stops when the
moving-average weight reaches the requested water volume.

Water assumption:
`1 mL water ~= 1 g`

Vibration handling:
The sketch does not trust load-cell readings while a pump is running. It tares
with the pumps off, runs one short pump burst, stops the pump, waits for the
scale to settle, then takes the moving-average reading.

Emergency stop:
Before every dose, all four load cells are tared with their cups/containers in
place. After every pump burst, the sketch checks all four load cells. If any
settled average is below `-0.50 g`, every pump is stopped and the dose is
aborted. This small negative threshold avoids false trips from normal load-cell
noise around zero.

Useful commands:

| Command | Meaning |
| --- | --- |
| `dose 20` | Pump 2 into LCA1 until about `20 g`, or `20 mL`, is measured |
| `dose 2 1 20` | Pump 2, load cell 1, target `20 mL` |
| `read 1` | Read LCA1 with the moving-average filter |
| `tare 1` | Tare LCA1 with the empty cup in place |
| `stop` | Abort an active dose |

## 4.6. Mixing Reservoir Mass-Balance Test

Sketch:
`fadex_mixing_mass_balance_test/fadex_mixing_mass_balance_test.ino`

Purpose:
This verifies that liquid leaving the nicotine/source and diluent/source
reservoirs appears in the mixing reservoir. For this test, both source liquids
can be water.

Default load-cell map:

| Load Cell | Role |
| --- | --- |
| LCA1 | Nicotine/source reservoir |
| LCA2 | Diluent/source reservoir |
| LCA3 | Mixing reservoir |
| LCA4 | Spare / optional |

The sketch tares all load cells before delivery with full source reservoirs and
an empty mixing reservoir already in place. Source reservoirs then read negative
as liquid leaves them. The code compares:

```text
total source mass lost ~= mixing reservoir mass gained
```

Useful commands:

| Command | Meaning |
| --- | --- |
| `MIXONE 1 20` | Run only Pump 1 until about `20 mL` leaves source 1 |
| `MIXONE 2 20` | Run only Pump 2 until about `20 mL` leaves source 2 |
| `MIXTEST 10 20` | Pump 10 mL from source 1 and 20 mL from source 2 |
| `MIXTEST 20 10` | Pump 20 mL from source 1 and 10 mL from source 2 |
| `MIXTEST 15 15` | Equal-volume source test |
| `READ` | Print settled weights from all load cells |
| `TARE` | Tare all load cells with reservoirs in place |
| `STOP` | Stop all pumps immediately |

During the test, the terminal prints `LIVE WEIGHTS` after every pump burst.
Those readings are taken only while all pumps are off, so the numbers are
slower but less distorted by motor vibration. `MIXTEST` still runs only one
pump at a time: Pump 1 finishes first, then Pump 2 starts.

If the ESP32 reboots during the test, check the first line printed after
startup. The sketch reports the last reset reason. If it says `brownout`, the
pump supply/noise is likely pulling the ESP32 power rail down.

Passing condition:
The default tolerance is `5%` of the requested total mass or `1.0 g`, whichever
is larger.

## 5. UV LED PWM Test

Sketch:
`fadex_uv_led_pwm_test/fadex_uv_led_pwm_test.ino`

Important PCB note:
The schematic routes `UVLEDPWM` to `GPIO39`, but `GPIO39` is input-only on the
ESP32. It can read a voltage, but it cannot generate PWM.

Current workaround:
Use the existing jumper plan from an output-capable pin such as `GPIO32` to the
`UVLEDPWM` / LED-driver control net, then run the PWM test sketch.

## 5.5. UNCS Vitamin C Concentration Test

Sketch:
`fadex_homebase_final_blynk/fadex_homebase_final_blynk.ino`

The final homebase firmware now includes the UNCS concentration math and reads
the photodiode/TIA output on `PDO / GPIO36`.

Demo commands:

| Command | Meaning |
| --- | --- |
| `UNCS DARK` | LED off, capture detector dark voltage |
| `UNCS BLANK` | LED on with `0 mM` water blank, capture blank voltage |
| `UNCS SAMPLE` | LED on with Vitamin C sample, calculate concentration |
| `UNCS PWM 50` | Set UV LED duty cycle to `50%` |
| `UNCS STATUS` | Print stored voltages and latest concentration |

Calculation:

```cpp
T = (v_sample - v_dark) / (v_blank - v_dark)
A = -log10(T)
C_mM = (A / 0.241) ^ 2.0964
```

TIA / optical gain guidance:

If `V_blank - V_dark` is too small, the detector is not seeing enough usable
light, so increase LED duty, improve alignment, or increase TIA gain. If
`V_blank` is near `3.0 V`, the ADC may be close to saturation, so lower LED
duty or reduce TIA gain.

## 6. Full Homebase Firmware

Sketch:
`fadex_homebase_final_blynk/fadex_homebase_final_blynk.ino`

The full firmware now uses the PCB pump pin map:

| Pump | Connector | IN1 net / Arduino pin | IN2 net / Arduino pin |
| --- | --- | --- | --- |
| Nicotine / Pump 1 | J7 | `3190.1.IN1` / GPIO22 | `3190.1.IN2` / GPIO21 |
| Diluent / Pump 2 | J4 | `3190.2.IN1` / GPIO19 | `3190.2.IN2` / GPIO18 |
| Mixing / Pump 3 | J9 | `3190.3.IN1` / GPIO33 | `3190.3.IN2` / GPIO4 |

On startup, the serial monitor prints the homebase Wi-Fi STA MAC so the
handheld can be paired later.

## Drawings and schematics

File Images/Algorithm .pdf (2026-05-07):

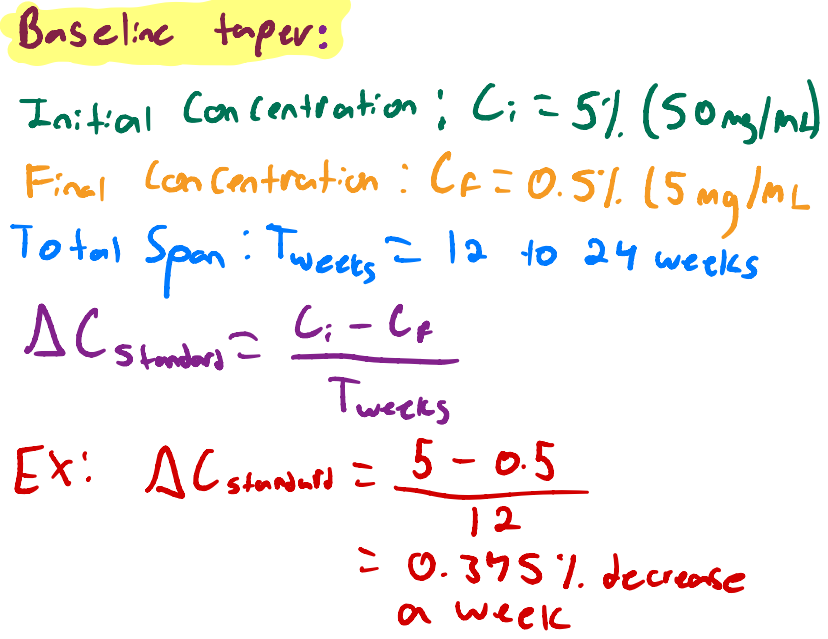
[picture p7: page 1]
Baseline tager:; Final Concentration : (f = 0.; 5% (5mg/mt Total Span : Tweeks = 12 to 24 weeks; standara i s; Alstunburs=; 375 % decrease; a week

Initial Concentration : Li = 5% (Songland

gager sent.

### Average : 172 pufts

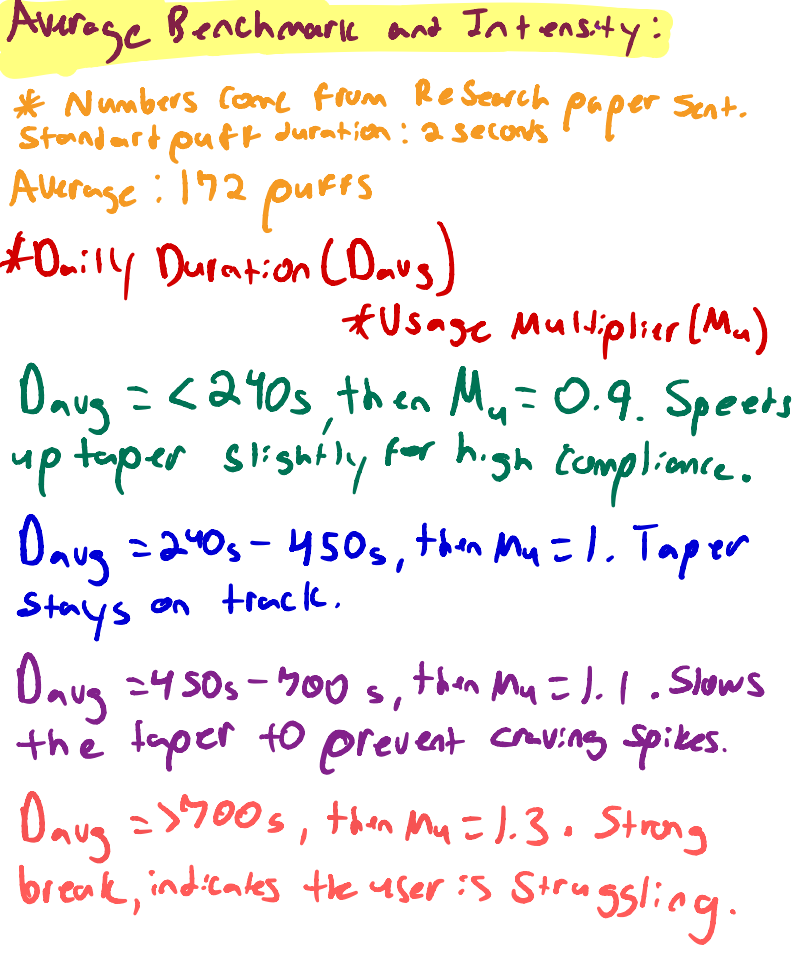
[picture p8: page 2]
then My = 0.; Speers; then Mu = 1 .; Taper; stays on; track .; Slows; Dang =1700s , then Mu = 1 .; Strong; break,

Average Benchmark and Intensity :

* Numbers Come from Research

Standard puff duration : 2Seconds

#Daily Duration (Davs)

*Usage Multiplier (Mu)

Darg =< 240s ,
p taper slightly for high Compliance .
Daug = 240s -
Darg =450s-700s ,
the taper to prevent craving spikes.
indicates the user is struggling .

- 1]

### Survey Answer Value (S)

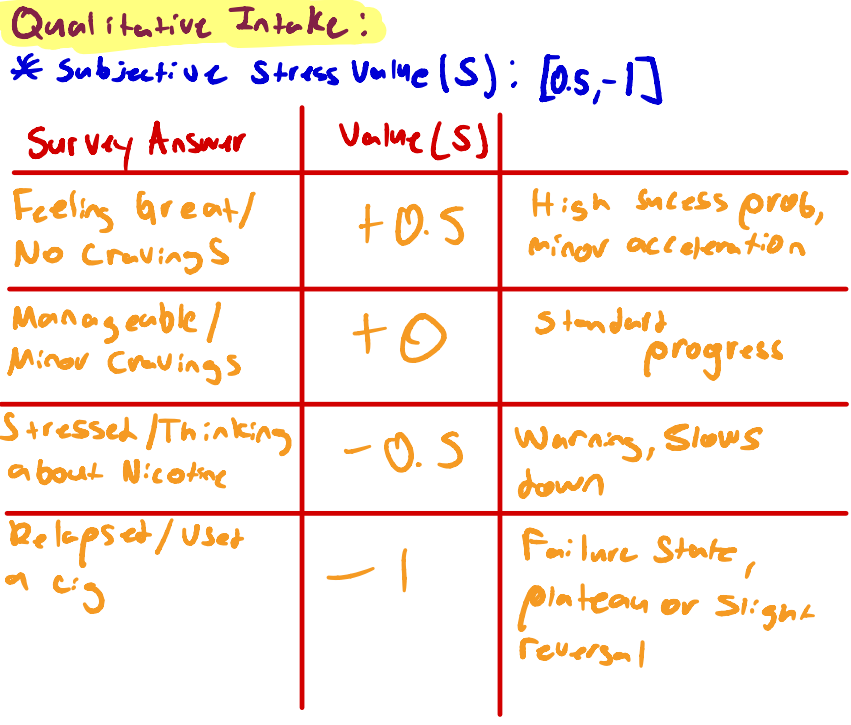
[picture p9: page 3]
Feeling Great/; High success prob,; No cravings; Minor acceleration; Manageable /; Standard; Minor Cravings; progress; Stressed/Thinking; Warning,; Slows; about Nicotine; town; Relagset/User; Failure State , a; zig; Plateau or Slight; reversal

Qualitative Intake :
* Subjective Stress Value (S) : [0.5,

## # Adaptive Multiplier ⁽A) : A= (1+S) +Cl ⁻

Mu)

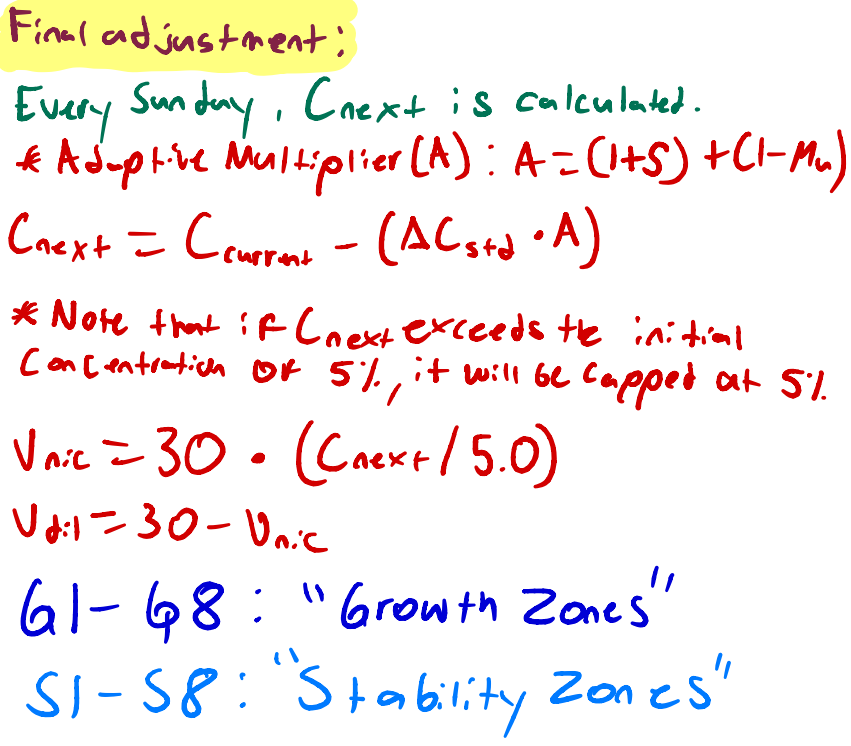
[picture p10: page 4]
Final adjustment :; Every Sunday ,; Cnext is calculated .; Cnext = Current -; (ACs +y ·; (Cnex + 15.; "Growth Zones"

* Note that :f(nextexceeds the initial
Concentration of 5%, it will be capped at S%.
Vnic =30 ·
Util =30-Unic
S1-58 : "Stability Zones"

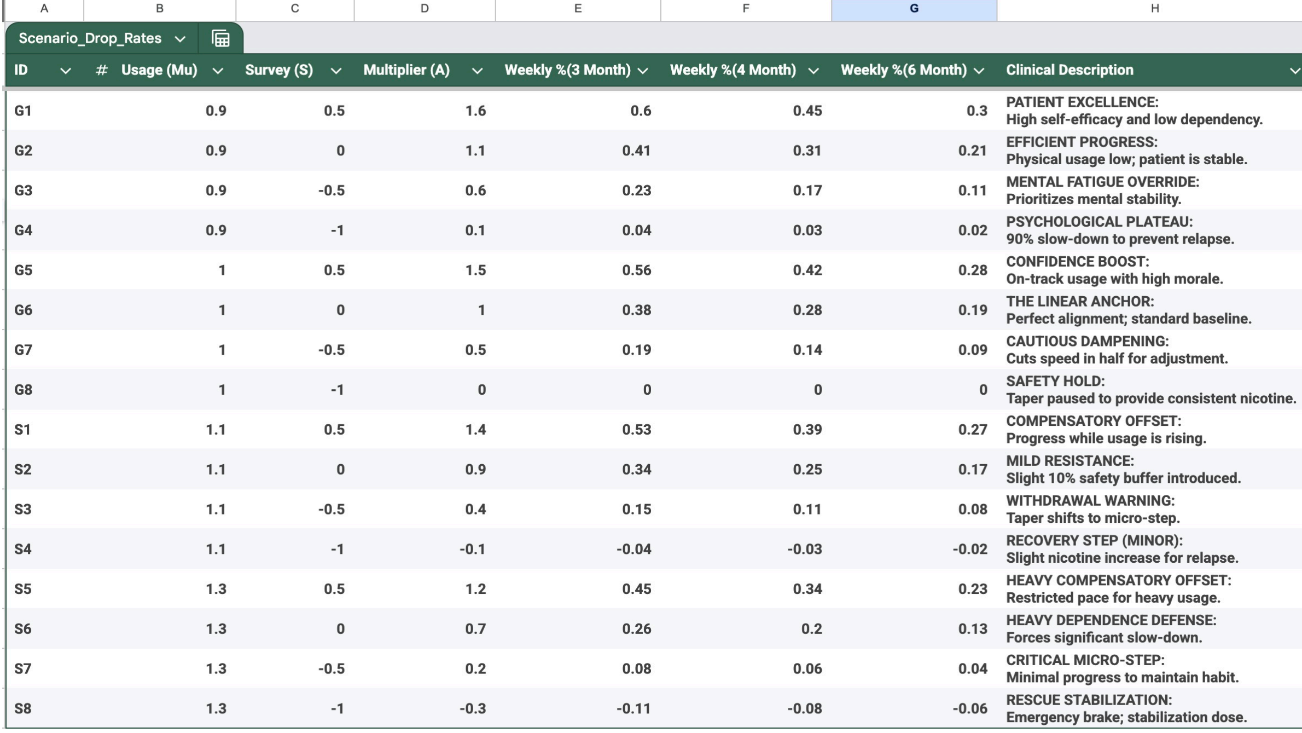
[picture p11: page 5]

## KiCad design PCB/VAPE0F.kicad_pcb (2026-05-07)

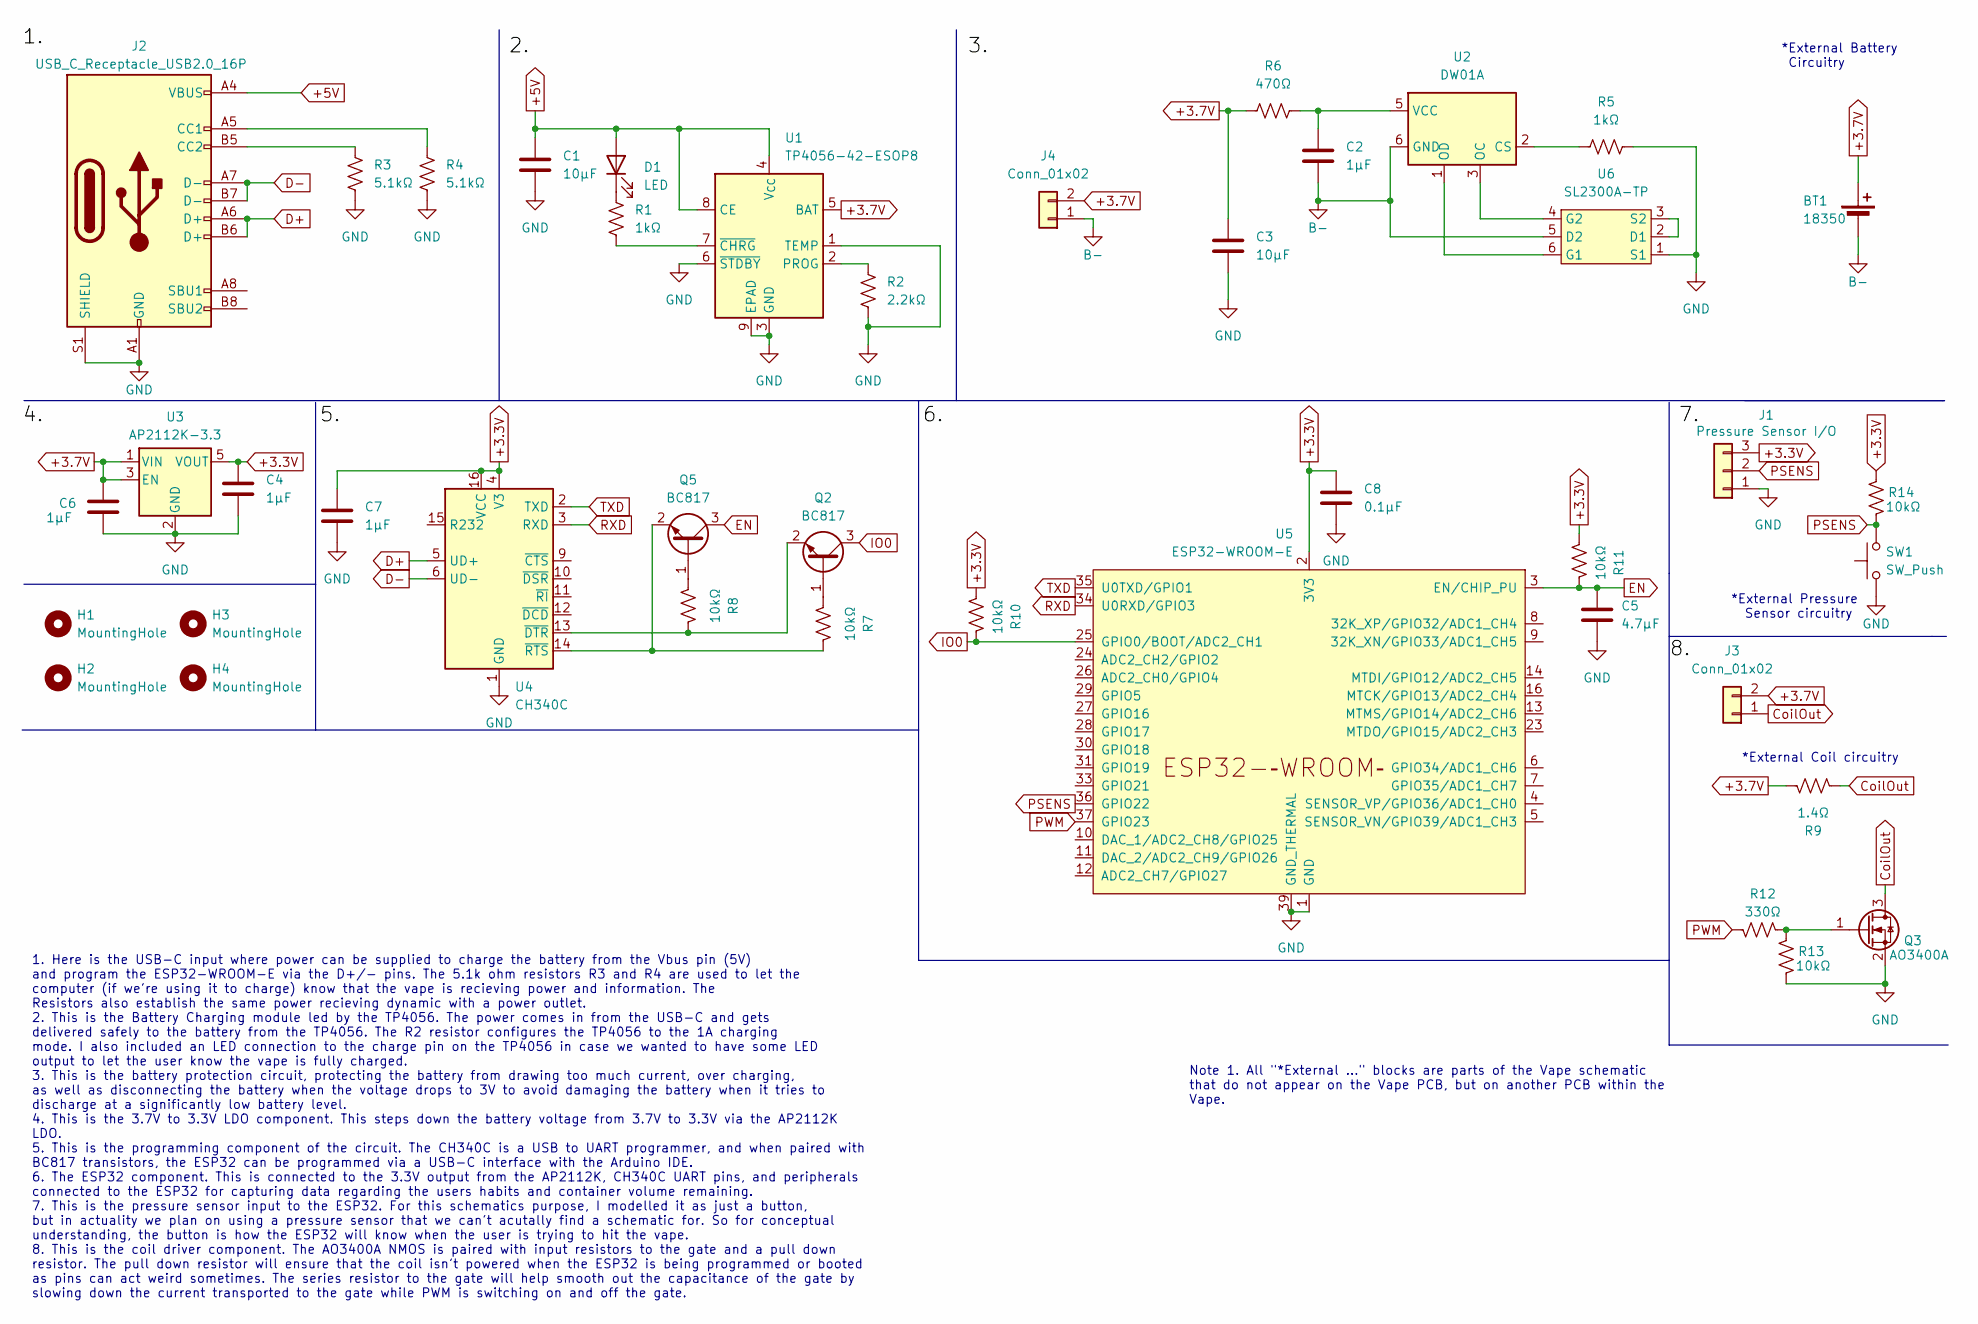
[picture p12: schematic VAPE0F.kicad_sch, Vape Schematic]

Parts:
BT1: 18350
C1, C3: 10μF; C_0805_2012Metric_Pad1.18x1.45mm_HandSolder
C2, C4, C6, C7: 1μF; C_0805_2012Metric_Pad1.18x1.45mm_HandSolder
C5: 4.7μF; C_0805_2012Metric_Pad1.18x1.45mm_HandSolder
C8: 0.1μF; C_0805_2012Metric_Pad1.18x1.45mm_HandSolder
D1: LED; LED_0805_2012Metric_Pad1.15x1.40mm_HandSolder
H1, H2, H3, H4: MountingHole; MountingHole_3.2mm_M3
J1: Pressure Sensor I/O; Molex_KK-254_AE-6410-03A_1x03_P2.54mm_Vertical
J2: USB_C_Receptacle_USB2.0_16P; USB_C_Receptacle_HRO_TYPE-C-31-M-12
J3, J4: Conn_01x02; Molex_KK-254_AE-6410-02A_1x02_P2.54mm_Vertical
Q2, Q5: BC817; SOT-23
Q3: AO3400A; SOT-23
R1, R5: 1kΩ; R_0805_2012Metric_Pad1.20x1.40mm_HandSolder
R2: 2.2kΩ; R_0805_2012Metric_Pad1.20x1.40mm_HandSolder
R3, R4: 5.1kΩ; R_0805_2012Metric_Pad1.20x1.40mm_HandSolder
R6: 470Ω; R_0805_2012Metric_Pad1.20x1.40mm_HandSolder
R7, R8, R10, R11, R13, R14: 10kΩ; R_0805_2012Metric_Pad1.20x1.40mm_HandSolder
R9: 1.4Ω; R_0805_2012Metric_Pad1.20x1.40mm_HandSolder
R12: 330Ω; R_0805_2012Metric_Pad1.20x1.40mm_HandSolder
SW1: SW_Push
U1: TP4056-42-ESOP8; SOIC-8-1EP_3.9x4.9mm_P1.27mm_EP2.41x3.3mm_ThermalVias
U2: DW01A; SOT-23-6
U3: AP2112K-3.3; SOT-23-5
U4: CH340C; SOIC-16_3.9x9.9mm_P1.27mm
U5: ESP32-WROOM-E; ESP32-WROOM-32E
U6: SL2300A-TP; SOT-23-6_Handsoldering

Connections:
+3.3V: C4.1, C7.1, C8.1, J1.3, R10.2, R11.2, R14.2, U3.5 (VOUT), U4.4 (V3), U4.16 (VCC), U5.2 (3V3)
+3.7V: BT1.1 (+), C3.1, C6.1, J3.2, J4.2, R6.1, R9.1, U1.5 (BAT), U3.1 (VIN), U3.3 (EN)
+5V: C1.1, D1.2 (A), J2.A4 (VBUS), J2.A9 (VBUS), J2.B4 (VBUS), J2.B9 (VBUS), U1.4 (V_{CC}), U1.8 (CE)
B-: BT1.2 (-), C2.2, J4.1, U2.6 (GND), U6.5 (D2)
CoilOut: J3.1, Q3.3 (D), R9.2
D+: J2.A6 (D+), J2.B6 (D+), U4.5 (UD+)
D-: J2.A7 (D-), J2.B7 (D-), U4.6 (UD-)
EN: C5.1, Q5.3 (C), R11.1, U5.3 (EN/CHIP_PU)
GND: C1.2, C3.2, C4.2, C5.2, C6.2, C7.2, C8.2, J1.1, J2.A1 (GND), J2.A12 (GND), J2.B1 (GND), J2.B12 (GND), J2.S1 (SHIELD), Q3.2 (S), R2.2, R3.2, R4.2, R5.2, R13.1, SW1.1, U1.1 (TEMP), U1.3 (GND), U1.6 (~STDBY), U1.9 (EPAD), U3.2 (GND), U4.1 (GND), U5.1 (GND), U5.15 (GND), U5.38 (GND), U5.39 (GND_THERMAL), U6.1 (S1)
IO0: Q2.3 (C), R10.1, U5.25 (GPIO0/BOOT/ADC2_CH1)
unnamed: D1.1 (K), R1.1
unnamed: J2.A5 (CC1), R4.1
unnamed: J2.B5 (CC2), R3.1
unnamed: Q2.1 (B), R7.2
unnamed: Q2.2 (E), R8.1, U4.13 (~DTR)
unnamed: Q3.1 (G), R12.2, R13.2
unnamed: Q5.1 (B), R8.2
unnamed: Q5.2 (E), R7.1, U4.14 (~RTS)
unnamed: R2.1, U1.2 (PROG)
unnamed: R1.2, U1.7 (~CHRG)
unnamed: R5.1, U2.2 (CS)
unnamed: U2.3 (OC), U6.4 (G2)
unnamed: U2.1 (OD), U6.6 (G1)
unnamed: C2.1, R6.2, U2.5 (VCC)
unnamed: U6.2 (D1), U6.3 (S2)
PSENS: J1.2, R14.1, SW1.2, U5.36 (GPIO22)
PWM: R12.1, U5.37 (GPIO23)
RXD: U4.3 (RXD), U5.34 (U0RXD/GPIO3)
TXD: U4.2 (TXD), U5.35 (U0TXD/GPIO1)

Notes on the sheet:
*External Coil circuitry
*External Battery Circuitry
1. Here is the USB-C input where power can be supplied to charge the battery from the Vbus pin (5V) and program the ESP32-WROOM-E via the D+/- pins. The 5.1k ohm resistors R3 and R4 are used to let the computer (if we're using it to charge) know that the vape is recieving power and information. The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
Note 1. All "*External ..." blocks are parts of the Vape schematic that do not appear on the Vape PCB, but on another PCB within the Vape.
*External Pressure Sensor circuitry

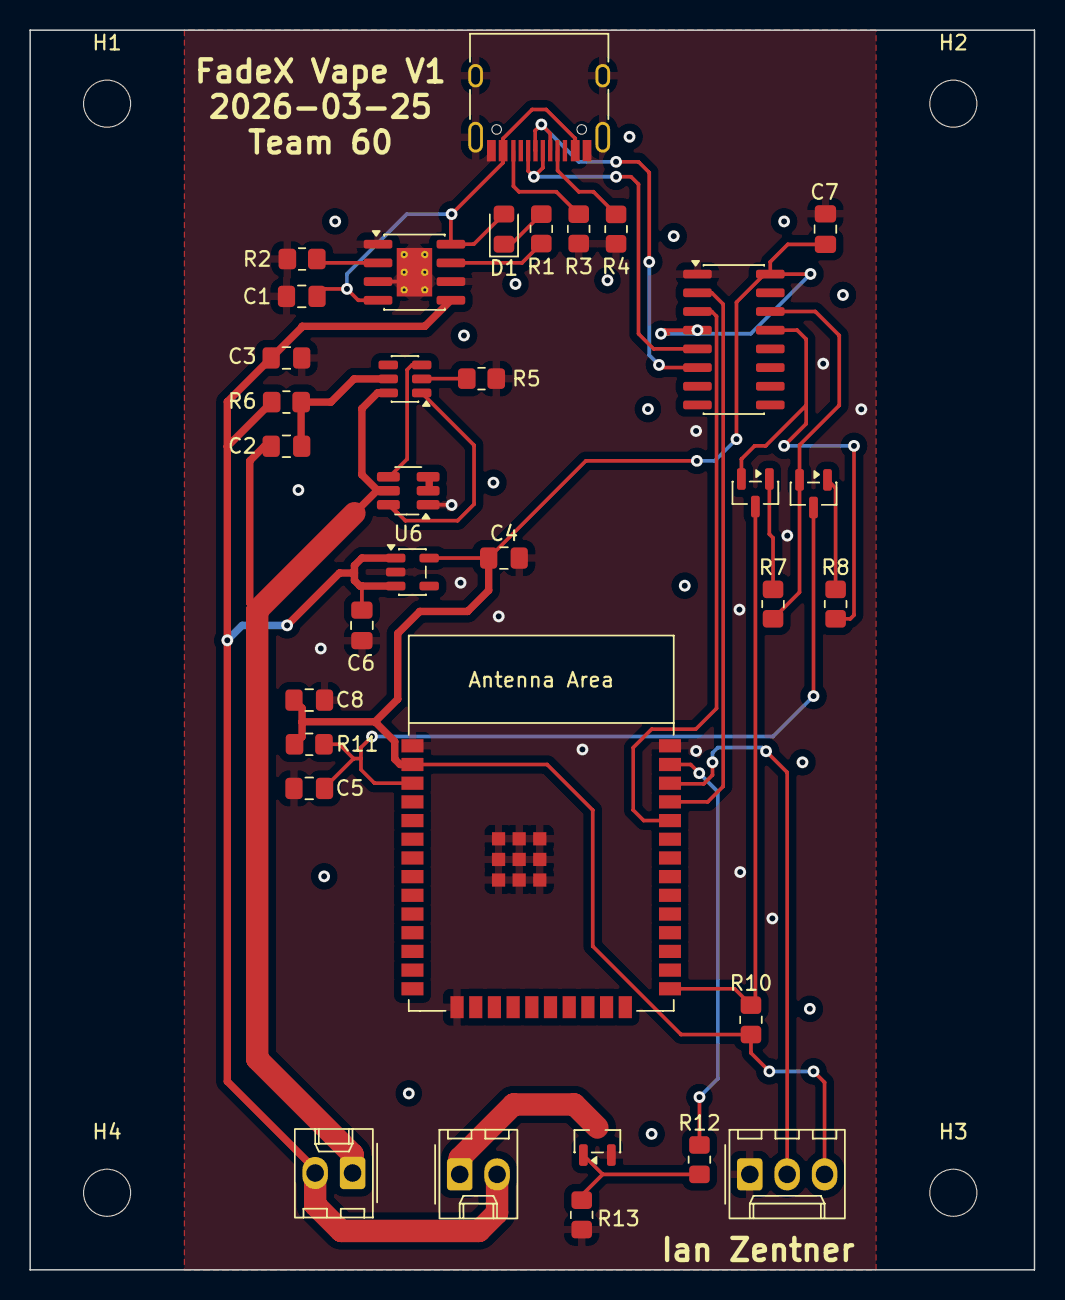
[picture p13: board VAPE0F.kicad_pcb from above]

Board: 2 copper layers, 68.2 x 84.2 mm, 38 parts (0 on the bottom side), 29 nets.

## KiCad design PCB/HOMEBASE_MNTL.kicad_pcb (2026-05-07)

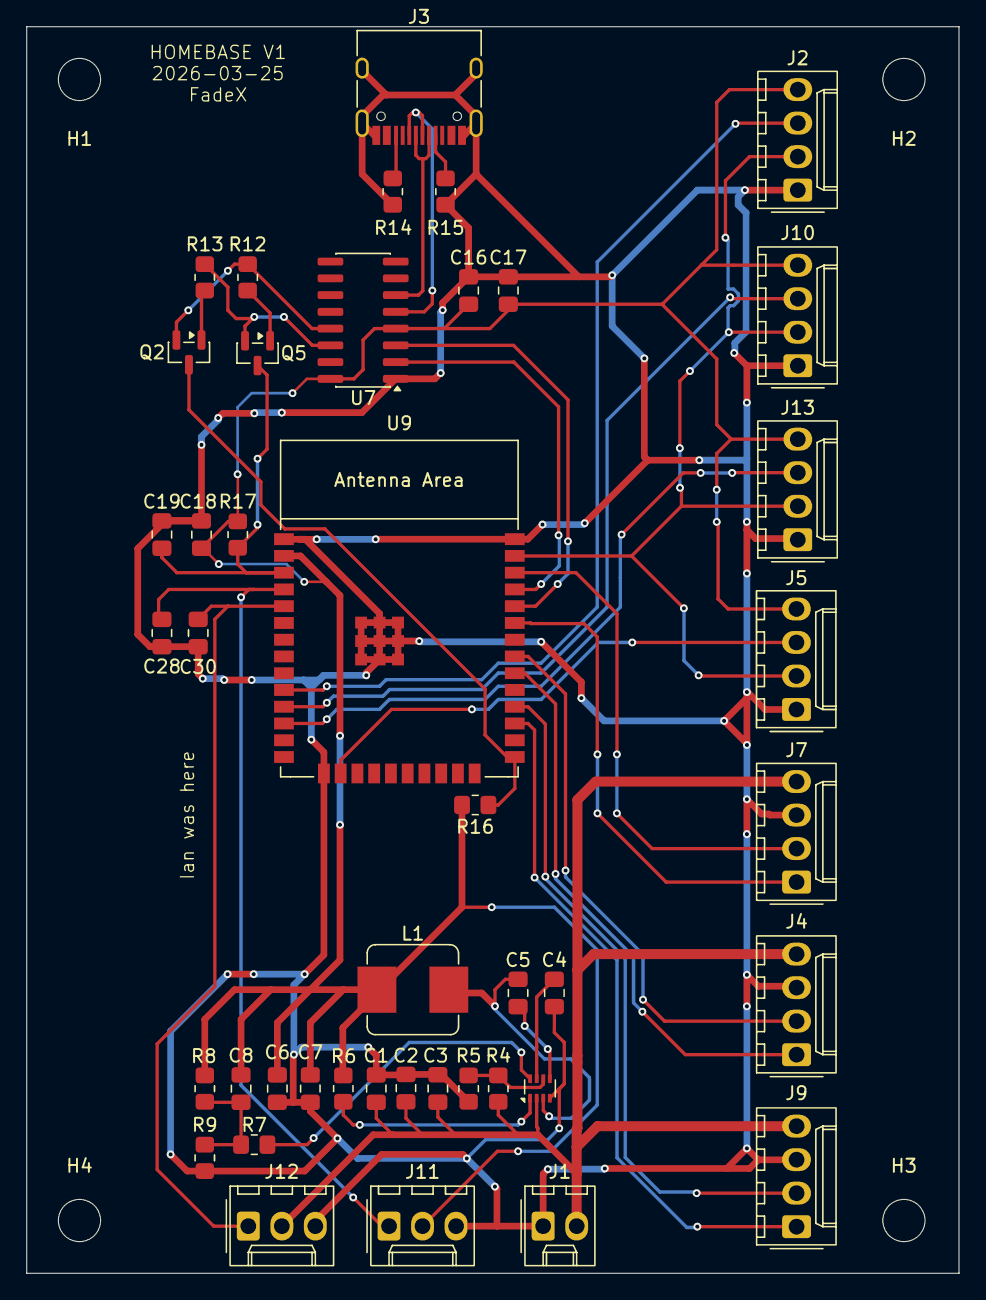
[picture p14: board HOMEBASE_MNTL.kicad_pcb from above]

Board: 2 copper layers, 70.7 x 94.5 mm, 47 parts (0 on the bottom side), 36 nets.

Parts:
C1, C2: 10μF; C_0805_2012Metric_Pad1.18x1.45mm_HandSolder
C3, C5, C18: 0.1μF; C_0805_2012Metric_Pad1.18x1.45mm_HandSolder
C4: 22nF; C_0805_2012Metric_Pad1.18x1.45mm_HandSolder
C6, C7: 22μF; C_0805_2012Metric_Pad1.18x1.45mm_HandSolder
C8: 470pF; C_0805_2012Metric_Pad1.18x1.45mm_HandSolder
C16, C17, C28, C30: 1μF; C_0805_2012Metric_Pad1.18x1.45mm_HandSolder
C19: 4.7μF; C_0805_2012Metric_Pad1.18x1.45mm_HandSolder
H1, H2, H3, H4: MountingHole; MountingHole_3.2mm_M3
J1: Conn_01x02; Molex_KK-254_AE-6410-02A_1x02_P2.54mm_Vertical
J2: Load Cell 1 Con.; Molex_KK-254_AE-6410-04A_1x04_P2.54mm_Vertical
J3: USB_C_Receptacle_USB2.0_16P; USB_C_Receptacle_HRO_TYPE-C-31-M-12
J4: Pump 2 Con.; Molex_KK-254_AE-6410-04A_1x04_P2.54mm_Vertical
J5: Load Cell 4 Con.; Molex_KK-254_AE-6410-04A_1x04_P2.54mm_Vertical
J7: Pump 1 Con.; Molex_KK-254_AE-6410-04A_1x04_P2.54mm_Vertical
J9: Pump 3 Con.; Molex_KK-254_AE-6410-04A_1x04_P2.54mm_Vertical
J10: Load Cell 2 Con.; Molex_KK-254_AE-6410-04A_1x04_P2.54mm_Vertical
J11: Photodiode Con.; Molex_KK-254_AE-6410-03A_1x03_P2.54mm_Vertical
J12: UVLED Con.; Molex_KK-254_AE-6410-03A_1x03_P2.54mm_Vertical
J13: Load Cell 3 Con.; Molex_KK-254_AE-6410-04A_1x04_P2.54mm_Vertical
L1: 6.8μH; L_Bourns_SRP7028A_7.3x6.6mm
Q2, Q5: BC817; SOT-23
R4: 191kΩ; R_0805_2012Metric_Pad1.20x1.40mm_HandSolder
R5: 49.9kΩ; R_0805_2012Metric_Pad1.20x1.40mm_HandSolder
R6: 100kΩ; R_0805_2012Metric_Pad1.20x1.40mm_HandSolder
R7, R12, R13, R16, R17: 10kΩ; R_0805_2012Metric_Pad1.20x1.40mm_HandSolder
R8: 51kΩ; R_0805_2012Metric_Pad1.20x1.40mm_HandSolder
R9: 9.09kΩ; R_0805_2012Metric_Pad1.20x1.40mm_HandSolder
R14, R15: 5.1kΩ; R_0805_2012Metric_Pad1.20x1.40mm_HandSolder
U2: MP2338GTL-P; SOT-583-8
U7: CH340C; SOIC-16_3.9x9.9mm_P1.27mm
U9: ESP32-WROOM-E; ESP32-WROOM-32E

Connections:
3.3V: C6.1, C7.1, C8.2, C16.1, C17.1, C18.1, J2.4, J5.4, J10.4, J11.2, J13.4, L1.2, R6.2, R8.2, R16.2, R17.2, U7.4 (V3), U7.16 (VCC), U9.2 (3V3)
12V: C1.1, C2.1, C3.1, J1.2, J4.4, J7.4, J9.4, J12.2, R4.1, U2.2 (VIN)
3190.1.IN1: J7.2, U9.36 (GPIO22)
3190.1.IN2: J7.1, U9.33 (GPIO21)
3190.2.IN1: J4.2, U9.31 (GPIO19)
3190.2.IN2: J4.1, U9.30 (GPIO18)
3190.3.IN1: J9.2, U9.28 (GPIO17)
3190.3.IN2: J9.1, U9.27 (GPIO16)
BST.3_3V: C5.1, U2.5 (BST)
D+: J3.A6 (D+), J3.B6 (D+), U7.5 (UD+)
D-: J3.A7 (D-), J3.B7 (D-), U7.6 (UD-)
DAT1: J2.3, U9.10 (DAC_1/ADC2_CH8/GPIO25)
DAT2: J10.3, U9.11 (DAC_2/ADC2_CH9/GPIO26)
DAT3: J13.3, U9.12 (ADC2_CH7/GPIO27)
DAT4: J5.3, U9.16 (MTCK/GPIO13/ADC2_CH4)
EN: C19.1, Q5.3 (C), R17.1, U9.3 (EN/CHIP_PU)
EN.3_3V: R4.2, R5.1, U2.6 (EN)
FB.3_3V: R7.1, U2.8 (FB)
GND: C1.2, C2.2, C3.2, C4.2, C6.2, C7.2, C16.2, C17.2, C18.2, C19.2, C28.2, C30.2, J1.1, J2.1, J3.A1 (GND), J3.A12 (GND), J3.B1 (GND), J3.B12 (GND), J3.S1 (SHIELD), J4.3, J5.1, J7.3, J9.3, J10.1, J11.3, J12.3, J13.1, R5.2, R9.2, R14.2, R15.2, U2.4 (GND), U7.1 (GND), U9.1 (GND), U9.15 (GND), U9.38 (GND), U9.39 (GND_THERMAL)
IO0: Q2.3 (C), R16.1, U9.25 (GPIO0/BOOT/ADC2_CH1)
unnamed: C8.1, R7.2, R8.1, R9.1
unnamed: J3.A5 (CC1), R15.1
unnamed: J3.B5 (CC2), R14.1
unnamed: J3.A4 (VBUS), J3.A9 (VBUS), J3.B4 (VBUS), J3.B9 (VBUS)
unnamed: Q2.1 (B), R13.2
unnamed: Q2.2 (E), R12.1, U7.13 (~DTR)
unnamed: Q5.1 (B), R12.2
unnamed: Q5.2 (E), R13.1, U7.14 (~RTS)
unnamed: C4.1, U2.7 (SS)
PDO: C28.1, J11.1, U9.4 (SENSOR_VP/GPIO36/ADC1_CH0)
PG.3_3V: R6.1, U2.1 (PG)
RXD: U7.3 (RXD), U9.34 (U0RXD/GPIO3)
SCLK: J2.2, J5.2, J10.2, J13.2, U9.37 (GPIO23)
SW.3_3V: C5.2, L1.1, U2.3 (SW)
TXD: U7.2 (TXD), U9.35 (U0TXD/GPIO1)
UVLEDPWM: C30.1, J12.1, U9.5 (SENSOR_VN/GPIO39/ADC1_CH3)

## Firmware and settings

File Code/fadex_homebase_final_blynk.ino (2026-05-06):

#define BLYNK_TEMPLATE_ID "TMPL2y04fShpL"
#define BLYNK_TEMPLATE_NAME "FadeX Homebase"
#define BLYNK_AUTH_TOKEN "-UXdaY64X3PrJmzBSJ-fNi3Phx6ySBni"

#define BLYNK_PRINT Serial

#include <Arduino.h>
#include <esp_now.h>
#include <esp_wifi.h>
#include <WiFi.h>
#include "esp_wpa2.h"
#include <math.h>
#include <string.h>

// Set to 1 for the final Wi-Fi + Blynk demo. Set to 0 only if the Blynk
// library is not installed and you need a Serial-Monitor-only fallback build.
#define FADEX_ENABLE_BLYNK_LIBRARY 1

#if FADEX_ENABLE_BLYNK_LIBRARY
#include <BlynkSimpleEsp32.h>
#else
#define V0 0
#define V1 1
#define V2 2
#define V3 3
#define V4 4
#define V5 5
#define V6 6
#define V7 7
#define V8 8
#define V9 9
#define V10 10
#define V11 11
#define V12 12
#define V13 13
#define V14 14
#define V15 15
#define V16 16
#define V17 17
#define V18 18
#define V19 19
#define V20 20
#define V21 21
#define V22 22
#define V23 23
#define V24 24
#define V25 25
#define V26 26
#define V27 27
#define V28 28

class FadeXDummyBlynk {
public:
  void run() {}
  bool connected() { return false; }
  void begin(const char *, const char *, const char *) {}
  void config(const char *) {}
  bool connect(unsigned long = 0) { return false; }

  template <typename... Args>
  void virtualWrite(Args...) {}

  template <typename... Args>
  void syncVirtual(Args...) {}

  template <typename... Args>
  void logEvent(Args...) {}
};

class BlynkTimer {
public:
  template <typename Callback>
  void setInterval(unsigned long, Callback) {}

  void run() {}
};

class WidgetTerminal {
public:
  explicit WidgetTerminal(int) {}
  void clear() {}
  void flush() {}
  void println() {}

  template <typename T>
  void println(const T &) {}
};

FadeXDummyBlynk Blynk;
#endif

// Set this to true for eduroam / university WPA2-Enterprise Wi-Fi.
// Set it to false if you go back to a normal hotspot or home router.
constexpr bool USE_ENTERPRISE_WIFI = false;

char ssid[] = "#212";
char pass[] = "graduate";

// WPA2-Enterprise credentials. Do not share your real password in chat.
// Some schools want "NetID@school.edu"; others want just "NetID".
char enterpriseIdentity[] = "mkelly61@illinois.edu";
char enterpriseUsername[] = "mkelly61@illinois.edu";
char enterprisePassword[] = "Pandabear2004!";

// Final demo mode: the homebase connects directly to Blynk through Wi-Fi,
// while the handheld sends puff sessions to the homebase over ESP-NOW.
constexpr bool USE_BLYNK_WIFI = true;
constexpr bool USE_BLYNK_USB_BRIDGE = false;
constexpr bool SERIAL_CHATBOT_ONLY = !USE_BLYNK_WIFI && !USE_BLYNK_USB_BRIDGE;

// IllinoisNet was observed on channel 11. When Blynk Wi-Fi is enabled, the
// homebase uses the AP channel automatically, so the handheld must match.
constexpr uint8_t ESPNOW_WIFI_CHANNEL = 11;

// PCB handheld/vape ESP32 STA MAC:
//   88:13:BF:55:35:F0
constexpr uint8_t EXPECTED_HANDHELD_MAC[6] = {
  0x88, 0x13, 0xBF, 0x55, 0x35, 0xF0
};

// the homebase receives the complete session packet that was collected
// on the handheld device
struct SessionData {
  uint32_t totalPuffs;     // number of puffs in the synced session
  float totalDuration;     // total puff duration in seconds
  float surveyScore;       // user self-report score
  uint8_t triggerCode;     // what the user said triggered the craving/use
  uint32_t sessionId;      // unique session ID
};

// short response packet sent back to the handheld for user feedback
struct SyncAck {
  bool accepted;
  uint32_t sessionId;
  float adaptiveMultiplier;
  float appliedConcentration;
  char scenarioId[4];
};

// one pump driver channel is represented by the two logic inputs that control
// the DRV8701 driver
struct PumpChannel {
  int in1;
  int in2;
  const char *name;
};

// each load-cell amplifier uses its own data line but shares one clock line
// with the other HX711 amplifiers. Because SCLK is shared, the final firmware
// reads the HX711 boards together instead of using one HX711 object at a time.
struct LoadCellChannel {
  int dataPin;
  float calibrationFactor;
  const char *name;
  const char *role;
  long tareOffset;
};

struct WeightSnapshot {
  bool valid;
  float nicReading;
  float dilReading;
  float mixReading;
  float nicLoss;
  float dilLoss;
  float totalSourceLoss;
  float mixingGain;
};

struct UncsMeasurement {
  bool valid;
  float sampleVoltage;
  float transmittance;
  float absorbance;
  float concentrationMm;
};

// values mirrored to the Blynk dashboard
struct DashboardState {
  float currentConcentrationPct;
  float nextConcentrationPct;
  uint32_t dailyPuffCount;
  float dailyDurationSec;
  float surveyScore;
  uint8_t triggerCode;
  uint8_t scenarioCode;
  bool relapseRiskHigh;
  float nicotineVolumeMl;
  float diluentVolumeMl;
  float moneySavedUsd;
  uint8_t milestoneProgressPct;
  uint8_t quitPlanWeeks;
  uint8_t currentTreatmentWeek;
  float plannedWeeklyStepPct;
};

// A calculated dose can wait here until the Blynk app tells the homebase to
// physically run the pumps. This makes demos safer because calculation and
// dispensing are separate actions.
struct PendingDose {
  bool ready;
  uint32_t sessionId;
  float appliedConcentrationPct;
  float nicotineVolumeMl;
  float diluentVolumeMl;
  unsigned long nicotineRunMs;
  unsigned long diluentRunMs;
};

enum GuidedTerminalState : uint8_t {
  TERMINAL_IDLE = 0,
  TERMINAL_WAITING_PLAN_DECISION,
  TERMINAL_WAITING_SURVEY,
  TERMINAL_WAITING_TRIGGER,
  TERMINAL_WAITING_PUFFS,
  TERMINAL_WAITING_RUN
};

// Final PCB pump-driver wiring:
// Pump 1 (nicotine) -> IN1 GPIO22, IN2 GPIO21
// Pump 2 (diluent)  -> IN1 GPIO19, IN2 GPIO18
// Pump 3 (mixing)   -> IN1 GPIO33, IN2 GPIO4
constexpr PumpChannel NICOTINE_PUMP = {22, 21, "Nicotine"};
constexpr PumpChannel DILUENT_PUMP = {19, 18, "Diluent"};
constexpr PumpChannel MIXING_PUMP = {33, 4, "Mixing"};

// Final PCB load-cell wiring:
// Shared HX711 clock -> GPIO23
// Data lines -> GPIO25, GPIO26, GPIO27, GPIO13
constexpr int HX711_SCK_PIN = 23;
constexpr int HX711_DATA1_PIN = 25;
constexpr int HX711_DATA2_PIN = 26;
constexpr int HX711_DATA3_PIN = 27;
constexpr int HX711_DATA4_PIN = 13;

// UNCS optical sensor wiring:
// PDO is the photodiode/TIA output into ESP32 ADC1_CH0.
// UVLEDPWM needs an output-capable pin. The PCB net was originally tied to
// GPIO39, which is input-only, so the demo assumes the jumper to GPIO32.
constexpr int UNCS_PHOTODIODE_ADC_PIN = 36;
constexpr int UNCS_UV_LED_PWM_PIN = 32;
constexpr uint8_t UNCS_PWM_CHANNEL = 0;
constexpr uint8_t UNCS_PWM_RESOLUTION_BITS = 10;
constexpr uint32_t UNCS_PWM_FREQUENCY_HZ = 200;
constexpr uint8_t UNCS_DEFAULT_LED_DUTY_PERCENT = 100;
constexpr size_t UNCS_ADC_SAMPLE_COUNT = 32;
constexpr unsigned long UNCS_LED_SETTLE_MS = 800;
constexpr unsigned long UNCS_ADC_PRINT_PERIOD_MS = 250;
constexpr unsigned long UNCS_AUTO_SHUTOFF_MS = 10000;
constexpr unsigned long UNCS_CIRC_DEFAULT_MS = 60000;
constexpr unsigned long UNCS_CIRC_MAX_MS = 120000;
constexpr float UNCS_DEFAULT_DARK_VOLTAGE = 0.142f;
constexpr float UNCS_MIN_LIGHT_WINDOW_V = 0.050f;
constexpr float UNCS_ADC_SATURATION_WARNING_V = 3.000f;
constexpr float UNCS_SURROGATE_MAX_MM = 10.0f;
constexpr float UNCS_TARGET_TOLERANCE_MM = 0.25f;
constexpr float UNCS_LARGE_ERROR_MM = 1.0f;
constexpr unsigned long UNCS_LARGE_PULSE_MS = 500;
constexpr unsigned long UNCS_SMALL_PULSE_MS = 100;
constexpr unsigned long UNCS_FLUSH_DELAY_MS = 3000;
constexpr uint8_t UNCS_MAX_ADJUSTMENT_STEPS = 30;
constexpr float MIXING_CHAMBER_MAX_SAFE_G = 100.0f;
constexpr float CALIB_A = 19.7487f;
constexpr float CALIB_B = 2.0964f;

// calibration and algorithm constants
constexpr float STARTING_CONCENTRATION_PERCENT = 5.0f;
constexpr float NIC_ML_PER_SEC = 0.98f;
constexpr float DIL_ML_PER_SEC = 0.98f;
constexpr float MAX_CONCENTRATION_PERCENT = 5.0f;
constexpr float MIN_CONCENTRATION_PERCENT = 0.5f;
constexpr float TOTAL_VOLUME_ML = 30.0f;
constexpr float TAPER_STEP_PERCENT = 0.28f;
constexpr float BASELINE_DAILY_COST_USD = 12.0f;
constexpr float BASELINE_DAILY_USAGE_SECONDS = 450.0f;
constexpr float MAX_USAGE_FACTOR_FOR_SAVINGS = 3.0f;
constexpr uint8_t DEFAULT_QUIT_PLAN_WEEKS = 12;
constexpr uint8_t MIN_QUIT_PLAN_WEEKS = 2;
constexpr uint8_t MAX_QUIT_PLAN_WEEKS = 24;

// stage 4 hardware timing helpers
// Set this false if you want to test only the Blynk/app flow. For the integrated
// homebase demo, it is true so the DRV8701 pump pins actually drive.
constexpr bool PUMPS_ENABLED = true;
// Pump 3 stays disabled for this demo. Pump 1 and Pump 2 feed the mixing
// reservoir, and LCA3 decides when each liquid target has been reached.
constexpr unsigned long MIXING_RUN_MS = 0;
constexpr unsigned long PRIME_RUN_MS = 3000;

// Calibrated with the 33.4 g reference mass on the PCB load-cell channels.
constexpr float LOADCELL1_CAL_FACTOR = 3053.60f;
constexpr float LOADCELL2_CAL_FACTOR = 3109.60f;
constexpr float LOADCELL3_CAL_FACTOR = 2951.40f;
constexpr float LOADCELL4_CAL_FACTOR = 2925.40f;

// LCA1/LCA2/LCA3 are used for the final demo:
// LCA1 = nicotine reservoir, LCA2 = diluent reservoir, LCA3 = mixing reservoir.
// LCA4 stays wired in the pin map, but it is not required for dose control.
constexpr uint8_t NIC_SOURCE_CELL_INDEX = 0;
constexpr uint8_t DIL_SOURCE_CELL_INDEX = 1;
constexpr uint8_t MIXING_CELL_INDEX = 2;
constexpr uint8_t MONITORED_CELL_COUNT = 3;
constexpr float WATER_GRAMS_PER_ML = 1.0f;
constexpr size_t MOVING_AVERAGE_SAMPLES = 4;
constexpr size_t TARE_SAMPLES = 20;
constexpr size_t TARE_VERIFY_SAMPLES = 8;
constexpr float TARE_ZERO_TOLERANCE_G = 0.05f;
constexpr unsigned long SCALE_SETTLE_MS = 350;
constexpr unsigned long HX711_SAMPLE_DELAY_MS = 25;
constexpr unsigned long HX711_READY_TIMEOUT_MS = 3000;
constexpr unsigned long MAX_SINGLE_PUMP_TIME_MS = 90000;

// Burst timing fills quickly while far from the target, then trims in shorter
// pulses so the scale has time to settle before the final dose mass.
constexpr float FAST_ZONE_G = 10.0f;
constexpr float MEDIUM_ZONE_G = 4.0f;
constexpr float SLOW_ZONE_G = 1.0f;
constexpr unsigned long FAST_BURST_MS = 1800;
constexpr unsigned long MEDIUM_BURST_MS = 650;
constexpr unsigned long SLOW_BURST_MS = 180;
constexpr unsigned long TRIM_BURST_MS = 45;
constexpr float MIXING_TARGET_TOLERANCE_G = 0.25f;

// Final delivery check: use the mixing reservoir because source loss was noisy
// in hardware testing. Final demo target must be within +/-0.5 g.
constexpr float DELIVERY_TOLERANCE_G = 0.5f;

// cloud / app timing helpers
constexpr unsigned long BLYNK_PUBLISH_INTERVAL_MS = 5000;

const char *const TRIGGER_LABELS[] = {
  "None", "Stress", "Social", "Habit",
  "Withdrawal", "Meals", "Driving", "Other"
};

const float SURVEY_VALUES[] = {0.5f, 0.0f, -0.5f, -1.0f};
const char *const SURVEY_LABELS[] = {
  "Better",
  "Neutral",
  "Struggling",
  "Worse"
};

// 4 usage tiers x 4 survey tiers = 16 named scenarios
const char *const SCENARIO_IDS[4][4] = {
  {"G1", "G2", "G3", "G4"},
  {"G5", "G6", "G7", "G8"},
  {"S1", "S2", "S3", "S4"},
  {"S5", "S6", "S7", "S8"}
};

// the homebase keeps track of the most recently applied concentration
float currentConcentration = STARTING_CONCENTRATION_PERCENT;
float cumulativeMoneySavedUsd = 0.0f;
uint8_t quitPlanWeeks = DEFAULT_QUIT_PLAN_WEEKS;
uint8_t currentTreatmentWeek = 1;

// one clinician override concentration can be pushed from the app
float clinicianOverridePct = -1.0f;
bool primeRequested = false;
bool doseStartRequested = false;
bool pumpStopRequested = false;
PendingDose pendingDose = {};

// App-only demo session. This lets Blynk act like the handheld by collecting
// puff count, puff duration, survey score, and trigger code directly.
SessionData appSession = {};
uint32_t nextAppSessionId = 100000;
bool appPuffActive = false;
unsigned long appPuffStartMs = 0;
GuidedTerminalState guidedTerminalState = TERMINAL_IDLE;

// UNCS stores the most recent dark, blank, and sample voltages so the demo can
// run one step at a time from the Serial Monitor or FadeX Chatbot.
float uncsDarkVoltage = UNCS_DEFAULT_DARK_VOLTAGE;
float uncsBlankVoltage = NAN;
float uncsSampleVoltage = NAN;
float uncsLastConcentrationMm = NAN;
uint8_t uncsLedDutyPercent = UNCS_DEFAULT_LED_DUTY_PERCENT;
uint8_t uncsActiveDutyPercent = 0;
bool uncsAdcStreaming = false;
unsigned long uncsLedTurnOnMs = 0;
unsigned long lastUncsAdcPrintMs = 0;

// used for event logging so the app does not get spammed
bool relapseEventLatched = false;
uint8_t lastMilestoneBucket = 0;

DashboardState dashboard = {
  STARTING_CONCENTRATION_PERCENT,
  STARTING_CONCENTRATION_PERCENT,
  0,
  0.0f,
  0.0f,
  0,
  1,
  false,
  TOTAL_VOLUME_ML,
  0.0f,
  0.0f,
  0,
  DEFAULT_QUIT_PLAN_WEEKS,
  1,
  (STARTING_CONCENTRATION_PERCENT - MIN_CONCENTRATION_PERCENT) /
    (DEFAULT_QUIT_PLAN_WEEKS - 1)
};

// the radio callback should stay short, so new work is dropped into this buffer
// and processed later in the main loop
volatile bool pendingSessionReady = false;
SessionData pendingSession = {};
uint8_t pendingSenderMac[6] = {};
portMUX_TYPE pendingMux = portMUX_INITIALIZER_UNLOCKED;

BlynkTimer timer;
WidgetTerminal fadeXChatbot(V22);

LoadCellChannel loadCells[] = {
  {HX711_DATA1_PIN, LOADCELL1_CAL_FACTOR, "LCA1", "Nic source reservoir", 0},
  {HX711_DATA2_PIN, LOADCELL2_CAL_FACTOR, "LCA2", "Diluent source reservoir", 0},
  {HX711_DATA3_PIN, LOADCELL3_CAL_FACTOR, "LCA3", "Mixing reservoir", 0},
  {HX711_DATA4_PIN, LOADCELL4_CAL_FACTOR, "LCA4", "Spare / optional", 0}
};

void publishTelemetryToBlynk();
void publishTelemetryToBridge();
void handleSerialCommands();
void processPendingPrimeRequest();
void processPendingDoseStartRequest();
void printLoadCellReadings();
bool tareLoadCells(bool requireZeroVerification = false);
void resetAppSession();
void clearAppSessionScratchpad();
void processAppSessionAndRunDose();
void processSession(const SessionData &data, const uint8_t *senderMac);
void stageHandheldSessionForSurvey(const SessionData &data, const uint8_t *senderMac);
void setAppSurveyScore(float surveyScore);
void setAppTriggerCode(int triggerCode);
float snapSurveyScore(float surveyScore);
const char *surveyLabel(float surveyScore);
const char *triggerLabel(uint8_t triggerCode);
float computePlannedWeeklyStep(float currentConcentrationPct);
void resetQuitPlan(uint8_t requestedWeeks);
void logToBlynkTerminal(const String &line);
void clearBlynkTerminal();
void executeConsoleCommand(String command, bool fromBlynkTerminal);
bool isStopCommand(const String &commandUpper);
bool stopRequestedFromSerial();
String appSessionStatusLine();
void promptGuidedTerminalState();
void beginGuidedTerminalSession();
void beginPreDoseSurveyFlow();
bool parseSurveyText(const String &commandUpper, float &surveyScore);
bool parseTriggerText(const String &commandUpper, int &triggerCode);
const char *guidedStateLabel(GuidedTerminalState state);
void showChatbotWelcome();
void setupUncsSensor();
void executeUncsCommand(String command, bool fromBlynkTerminal);
void setUncsLed(bool enabled);
void publishUncsTelemetry();
void runPump(const PumpChannel &pump, unsigned long runMs);
void stopPump(const PumpChannel &pump);
void stopAllPumps();
void runPumpForward(const PumpChannel &pump);
WeightSnapshot readWeightSnapshot();
float scaleNicotinePercentToSurrogateMm(float nicotinePercent);
float calculateConcentration(float absorbance);
float calculateUncsAbsorbance(float darkVoltage,
                              float blankVoltage,
                              float sampleVoltage);
float calculateUncsConcentrationMm(float darkVoltage,
                                   float blankVoltage,
                                   float sampleVoltage);
UncsMeasurement readUncsMeasurement();
bool runUncsSurrogateControl(float targetMm,
                             const String &targetLabel,
                             bool fromBlynkTerminal);
float readUncsPhotodiodeVoltage();
bool runWeightControlledDose(float nicotineMl, float diluentMl);
void runMixingMassBalanceTest(float nicMl, float dilMl);
void runSinglePumpMassBalanceTest(uint8_t pumpNumber, float targetMl);

// keep Blynk responsive while long pump runs are happening
void serviceCloud() {
  if (USE_BLYNK_WIFI) {
    Blynk.run();
  }
  timer.run();
}

void printMacAddress(const uint8_t *mac) {
  for (uint8_t i = 0; i < 6; ++i) {
    if (i > 0) {
      Serial.print(":");
    }
    if (mac[i] < 0x10) {
      Serial.print("0");
    }
    Serial.print(mac[i], HEX);
  }
}

String bridgeEscaped(String text) {
  text.replace("\\", "\\\\");
  text.replace("\r", "");
  text.replace("\n", "\\n");
  return text;
}

void bridgeSetPin(const char *pin, const String &value) {
  if (!USE_BLYNK_USB_BRIDGE) {
    return;
  }

  Serial.print("BRIDGE_SET ");
  Serial.print(pin);
  Serial.print(" ");
  Serial.println(bridgeEscaped(value));
}

void clearBlynkTerminal() {
  if (SERIAL_CHATBOT_ONLY) {
    Serial.println();
    Serial.println("--------------------------------------------------");
    return;
  }

  bridgeSetPin("v23", "");

  if (!Blynk.connected()) {
    return;
  }

  fadeXChatbot.clear();
  fadeXChatbot.flush();
  Blynk.virtualWrite(V22, "clr");
}

void renderBlynkTerminalText(const String &text) {
  if (SERIAL_CHATBOT_ONLY) {
    Serial.println();
    Serial.println("FadeX Chatbot:");
    Serial.println(text);
    Serial.println("--------------------------------------------------");
    return;
  }

  bridgeSetPin("v23", text);

  if (!Blynk.connected()) {
    return;
  }

  Blynk.virtualWrite(V23, text);
  fadeXChatbot.println();

  int start = 0;
  while (start <= text.length()) {
    const int newlineIndex = text.indexOf('\n', start);
    if (newlineIndex < 0) {
      fadeXChatbot.println(text.substring(start));
      break;
    }

    fadeXChatbot.println(text.substring(start, newlineIndex));
    start = newlineIndex + 1;
  }

  fadeXChatbot.flush();
}

void logToBlynkTerminal(const String &line) {
  renderBlynkTerminalText(line);
}

void showChatbotWelcome() {
  renderBlynkTerminalText(
    "Welcome to FadeX Chatbot.\n"
    "I can help check in before your next dose.\n"
    "Type START to begin, or STATUS to see the current session.\n" +
    appSessionStatusLine()
  );
}

String appSessionStatusLine() {
  String line =
    String("Current status | conc=") + String(currentConcentration, 2) +
    "% | week " + String(static_cast<int>(currentTreatmentWeek)) +
    "/" + String(static_cast<int>(quitPlanWeeks)) +
    " | puffs=" + String(appSession.totalPuffs) +
    " | duration=" + String(appSession.totalDuration, 1) + " s" +
    " | survey=" + String(surveyLabel(appSession.surveyScore)) +
    " | trigger=" + String(triggerLabel(appSession.triggerCode));

  if (pendingDose.ready) {
    line += " | dose ready";
  }

  return line;
}

bool appSessionHasPuffMetrics() {
  return appSession.totalPuffs > 0 || appSession.totalDuration >= 0.05f;
}

bool isWeekOneBaselineFlow() {
  return currentTreatmentWeek <= 1;
}

void promptForPuffMetricsBeforeDose() {
  guidedTerminalState = TERMINAL_WAITING_PUFFS;
  const String prompt =
    isWeekOneBaselineFlow()
      ? "Week 1 baseline: record puff metrics first.\n"
        "Use the Puff button or type PUFF <seconds>.\n"
        "Then I will ask check-in questions to calculate the week 2 dose.\n"
      : "Record puff metrics first.\n"
        "Use the Puff button or type PUFF <seconds>.\n"
        "After usage is recorded, I will ask the check-in questions.\n";

  renderBlynkTerminalText(prompt + appSessionStatusLine());
}

void calculateAndRunAppDoseFromGuidedFlow() {
  if (!appSessionHasPuffMetrics()) {
    promptForPuffMetricsBeforeDose();
    return;
  }

  guidedTerminalState = TERMINAL_IDLE;
  renderBlynkTerminalText(
    "Check-in complete. Calculating and dispensing the dose now.\n" +
    appSessionStatusLine()
  );
  processAppSessionAndRunDose();
}

bool parseSurveyText(const String &commandUpper, float &surveyScore) {
  if (commandUpper.indexOf("BETTER") >= 0) {
    surveyScore = 0.5f;
    return true;
  }
  if (commandUpper.indexOf("NEUTRAL") >= 0) {
    surveyScore = 0.0f;
    return true;
  }
  if (commandUpper.indexOf("STRUGGL") >= 0) {
    surveyScore = -0.5f;
    return true;
  }
  if (commandUpper.indexOf("WORSE") >= 0) {
    surveyScore = -1.0f;
    return true;
  }
  return false;
}

bool parseTriggerText(const String &commandUpper, int &triggerCode) {
  if (commandUpper.indexOf("NONE") >= 0) {
    triggerCode = 0;
    return true;
  }
  if (commandUpper.indexOf("STRESS") >= 0) {
    triggerCode = 1;
    return true;
  }
  if (commandUpper.indexOf("SOCIAL") >= 0) {
    triggerCode = 2;
    return true;
  }
  if (commandUpper.indexOf("HABIT") >= 0) {
    triggerCode = 3;
    return true;
  }
  if (commandUpper.indexOf("WITHDRAW") >= 0) {
    triggerCode = 4;
    return true;
  }
  if (commandUpper.indexOf("MEAL") >= 0) {
    triggerCode = 5;
    return true;
  }
  if (commandUpper.indexOf("DRIV") >= 0) {
    triggerCode = 6;
    return true;
  }
  if (commandUpper.indexOf("OTHER") >= 0) {
    triggerCode = 7;
    return true;
  }
  return false;
}

const char *guidedStateLabel(GuidedTerminalState state) {
  switch (state) {
    case TERMINAL_WAITING_PLAN_DECISION: return "waiting_plan";
    case TERMINAL_WAITING_SURVEY: return "waiting_survey";
    case TERMINAL_WAITING_TRIGGER: return "waiting_trigger";
    case TERMINAL_WAITING_PUFFS: return "waiting_puffs";
    case TERMINAL_WAITING_RUN: return "waiting_run";
    default: return "idle";
  }
}
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
void loop() {
  serviceCloud();
  processUncsSafetyAndStreaming();
  processPendingPrimeRequest();
  processPendingDoseStartRequest();
  handleSerialCommands();

  SessionData session = {};
  uint8_t senderMac[6] = {};
  if (fetchPendingSession(session, senderMac)) {
    stageHandheldSessionForSurvey(session, senderMac);
  }
}

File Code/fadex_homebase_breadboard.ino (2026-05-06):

#include <esp_now.h>
#include <WiFi.h>

// Breadboard homebase using a three-pump ESP32 wiring setup:
// - receives puff count + duration from the handheld
// - asks the operator for survey score and trigger using the Serial Monitor
// - computes the taper algorithm
// - drives nicotine, diluent, and final-transfer pumps
// - supports direct volume-based calibration commands for Pumps 1 and 2
// - supports priming feed lines before a run
// - sends a short result packet back to the handheld

struct SessionData {
  uint32_t totalPuffs;
  float totalDuration;
  uint32_t sessionId;
};

struct SyncAck {
  bool accepted;
  uint32_t sessionId;
  float adaptiveMultiplier;
  float appliedConcentration;
  char scenarioId[4];
};

struct PumpChannel {
  int ena;
  int in1;
  int in2;
  const char *name;
};

// Three-pump breadboard layout on the ESP32.
constexpr PumpChannel PUMP1 = {25, 26, 27, "Pump 1 / Nicotine"};
constexpr PumpChannel PUMP2 = {14, 19, 18, "Pump 2 / Diluent"};
constexpr PumpChannel PUMP3 = {33, 32, 23, "Pump 3 / Final Transfer"};

// Multi-point calibration from recent water tests.
// The lag-based model fit the measurements better than a simple volume offset:
// runtime_seconds = startup_lag_seconds + (target_mL / steady_mL_per_sec)
constexpr float PUMP1_STEADY_ML_PER_SEC = 1.04f;
constexpr float PUMP2_STEADY_ML_PER_SEC = 1.04f;
constexpr float PUMP1_STARTUP_LAG_SEC = 1.26f;
constexpr float PUMP2_STARTUP_LAG_SEC = 1.26f;

constexpr float MAX_CONCENTRATION_PERCENT = 5.0f;
constexpr float MIN_CONCENTRATION_PERCENT = 0.5f;
constexpr float TOTAL_VOLUME_ML = 30.0f;
constexpr float TAPER_STEP_PERCENT = 0.28f;
constexpr unsigned long PRIME_PUMPS_12_MS = 10000;
constexpr unsigned long PUMP3_FINAL_TRANSFER_MS = 60000;

const char *const TRIGGER_LABELS[] = {
  "None", "Stress", "Social", "Habit",
  "Withdrawal", "Meals", "Driving", "Other"
};

const float SURVEY_VALUES[] = {0.5f, 0.0f, -0.5f, -1.0f};

// 4 usage tiers x 4 survey tiers = 16 scenarios.
const char *const SCENARIO_IDS[4][4] = {
  {"G1", "G2", "S1", "S2"},
  {"G3", "G4", "S3", "S4"},
  {"G5", "G6", "S5", "S6"},
  {"G7", "G8", "S7", "S8"}
};

float currentConcentration = 5.0f;

volatile bool pendingSessionReady = false;
SessionData pendingSession = {};
uint8_t pendingSenderMac[6] = {};
portMUX_TYPE pendingMux = portMUX_INITIALIZER_UNLOCKED;

// Keep the last response so a duplicate radio packet does not dose twice.
bool haveLastAck = false;
uint8_t lastSenderMac[6] = {};
SyncAck lastAck = {};

void printMacAddress() {
  uint8_t mac[6];
  WiFi.macAddress(mac);

  Serial.print("Homebase MAC: ");
  for (int i = 0; i < 6; ++i) {
    if (i > 0) {
      Serial.print(":");
    }
    if (mac[i] < 16) {
      Serial.print("0");
    }
    Serial.print(mac[i], HEX);
  }
  Serial.println();
}

void stopPump(const PumpChannel &pump) {
  analogWrite(pump.ena, 0);
  digitalWrite(pump.in1, LOW);
  digitalWrite(pump.in2, LOW);
}

void stopAllPumps() {
  stopPump(PUMP1);
  stopPump(PUMP2);
  stopPump(PUMP3);
}

void setupPumpDriver(const PumpChannel &pump) {
  pinMode(pump.ena, OUTPUT);
  pinMode(pump.in1, OUTPUT);
  pinMode(pump.in2, OUTPUT);
  stopPump(pump);
}

void startPump(const PumpChannel &pump) {
  digitalWrite(pump.in1, HIGH);
  digitalWrite(pump.in2, LOW);
  analogWrite(pump.ena, 255);
}

void runPump(const PumpChannel &pump, unsigned long runMs) {
  if (runMs == 0) {
    return;
  }

  Serial.print("Running ");
  Serial.print(pump.name);
  Serial.print(" for ");
  Serial.print(runMs);
  Serial.println(" ms");

  startPump(pump);
  delay(runMs);
  stopPump(pump);
}

void runPumpsSimultaneous(unsigned long pump1Ms, unsigned long pump2Ms) {
  if (pump1Ms == 0 && pump2Ms == 0) {
    Serial.println("Nothing to run. Both computed runtimes were zero.");
    return;
  }

  Serial.println("Starting simultaneous pump test.");
  Serial.print("Pump 1 runtime (ms): ");
  Serial.println(pump1Ms);
  Serial.print("Pump 2 runtime (ms): ");
  Serial.println(pump2Ms);

  bool pump1Active = pump1Ms > 0;
  bool pump2Active = pump2Ms > 0;

  if (pump1Active) {
    startPump(PUMP1);
  }
  if (pump2Active) {
    startPump(PUMP2);
  }

  const unsigned long startMs = millis();
  while (pump1Active || pump2Active) {
    const unsigned long elapsedMs = millis() - startMs;

    if (pump1Active && elapsedMs >= pump1Ms) {
      stopPump(PUMP1);
      pump1Active = false;
      Serial.println("Pump 1 stopped.");
    }

    if (pump2Active && elapsedMs >= pump2Ms) {
      stopPump(PUMP2);
      pump2Active = false;
      Serial.println("Pump 2 stopped.");
    }

    delay(1);
  }

  Serial.println("Simultaneous pump test finished.");
}

void primeFeedLines(unsigned long runMs) {
  if (runMs == 0) {
    Serial.println("Prime time must be greater than zero.");
    return;
  }

  Serial.println();
  Serial.println("Priming Pumps 1 and 2 together to fill the feed tubes.");
  runPumpsSimultaneous(runMs, runMs);
}

bool ensurePeerRegistered(const uint8_t *mac) {
  if (esp_now_is_peer_exist(mac)) {
    return true;
  }

  esp_now_peer_info_t peerInfo = {};
  memcpy(peerInfo.peer_addr, mac, 6);
  peerInfo.channel = 0;
  peerInfo.encrypt = false;
  return esp_now_add_peer(&peerInfo) == ESP_OK;
}

bool sameMac(const uint8_t *a, const uint8_t *b) {
  return memcmp(a, b, 6) == 0;
}

float clampDose(float value) {
  if (value < MIN_CONCENTRATION_PERCENT) {
    return MIN_CONCENTRATION_PERCENT;
  }
  if (value > MAX_CONCENTRATION_PERCENT) {
    return MAX_CONCENTRATION_PERCENT;
  }
  return value;
}

uint8_t classifyUsageTier(float totalDurationSeconds) {
  if (totalDurationSeconds < 240.0f) {
    return 0;
  }
  if (totalDurationSeconds <= 450.0f) {
    return 1;
  }
  if (totalDurationSeconds <= 700.0f) {
    return 2;
  }
  return 3;
}

float usageMultiplierForTier(uint8_t tier) {
  switch (tier) {
    case 0: return 0.9f;
    case 1: return 1.0f;
    case 2: return 1.1f;
    default: return 1.3f;
  }
}

const char *triggerLabel(uint8_t triggerCode) {
  const size_t triggerCount = sizeof(TRIGGER_LABELS) / sizeof(TRIGGER_LABELS[0]);
  if (triggerCode >= triggerCount) {
    return "Unknown";
  }
  return TRIGGER_LABELS[triggerCode];
}

void onDataRecv(const esp_now_recv_info *info, const uint8_t *incomingData, int len) {
  if (len != sizeof(SessionData)) {
    return;
  }

  portENTER_CRITICAL_ISR(&pendingMux);
  if (!pendingSessionReady) {
    memcpy(&pendingSession, incomingData, sizeof(pendingSession));
    memcpy(pendingSenderMac, info->src_addr, 6);
    pendingSessionReady = true;
  }
  portEXIT_CRITICAL_ISR(&pendingMux);
}

bool fetchPendingSession(SessionData &session, uint8_t senderMac[6]) {
  bool hasSession = false;

  portENTER_CRITICAL(&pendingMux);
  if (pendingSessionReady) {
    session = pendingSession;
    memcpy(senderMac, pendingSenderMac, 6);
    pendingSessionReady = false;
    hasSession = true;
  }
  portEXIT_CRITICAL(&pendingMux);

  return hasSession;
}
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

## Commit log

2026-05-06 Add subsystem breakdown entry for FadeX design
    Documented the subsystem breakdown and interactions for the FadeX device design, including objectives, work completed, results, decisions, and next steps.
2026-05-06 Add tolerance analysis entry for fluid delivery risks
    Documented tolerance analysis and fluid delivery risks for nicotine concentration control in vaping devices. Included objectives, work completed, results, decisions, next steps, and a supporting figure.
2026-05-06 Add PCB review preparation entry
    Documented preparation for PCB review, including objectives, completed work, decisions made, and next steps.
2026-05-06 Add entry on fluid mixing and concentration control
    Documented fluid-mixing equations and tolerance analysis for nicotine concentration control. Included calculations and results supporting the feasibility of pump-based mixing.
2026-05-06 Add notebook entry for PCB planning and parts ordering
    Documented PCB planning and parts ordering process, including objectives, work completed, decisions made, and next steps.
2026-05-06 Update entry on pump and chemical strategy
2026-05-06 Add spring break work planning entry
    Documented planning for spring break work to maintain project progress.
2026-05-06 Add notebook entry for spring break remote planning
    Documented spring break planning activities and decisions.
2026-05-06 Document PCB order and hardware planning details
    Added details about PCB ordering and hardware planning.
2026-05-06 Add entry for breadboard-to-PCB transition planning
    Documented planning for transitioning from breadboard to PCB testing, including objectives, work completed, results, and next steps.
2026-05-06 Add entry on GitHub and Kanban board coordination
    Documented team discussions on GitHub access and Kanban board usage for project coordination.
2026-05-06 Add entry on verification and flowchart planning
    Documented verification planning and flowchart organization for the FadeX algorithm, including subsystem integration and verification tests.
2026-05-06 Add entry for mock presentation slide planning
    Documented mock presentation planning for project objectives and algorithm flow.
2026-05-06 Create entry for algorithm and stage visuals
    Added detailed entry about algorithm and stage visual development for project presentation.
2026-05-06 Add demo flow entry for Blynk and FadeX Chatbot
    Documented the demo flow using Blynk and the FadeX Chatbot, detailing objectives, work completed, results, and next steps.
2026-05-06 Add entry for final demo setup on 4/27/26
    Documented the final demo setup and system readiness for the FadeX prototype, including objectives and completed work.
2026-05-07 Revise README with detailed project information
    Expanded project overview, team roles, and detailed prototype architecture. Added sections on tapering algorithm, repository structure, subsystem tests, safety notes, and final deliverables.
2026-05-07 Update README to remove folder references
    Removed references to Software, CAD, and Datasheets folders.
2026-05-07 Post-Spring-Break Project Reset
    Removed suggested figure for post-spring-break task board.
2026-05-07 PCB Order and Hardware Availability Planning
    Removed the suggested figure reference for PCB pinout planning.
2026-05-07 Algorithm Flowchart and Documentation Update
2026-05-07 Remove suggested figure from notebook entryBreadboard-to-PCB Transition Planning
    Removed suggested figure description from the notebook entry.
2026-05-07 Breadboard-to-PCB Transition Planning
2026-05-07 Verification and Flowchart Planning
    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
2026-05-07 Algorithm and Stage Visual Development
2026-05-07 Blynk Dashboard and Chatbot Demo Flow
    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
